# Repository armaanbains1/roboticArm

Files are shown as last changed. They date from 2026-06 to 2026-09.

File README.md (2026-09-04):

# Autonomous Object Tracking Robotic Arm

An autonomous eye-to-hand robotic pick-and-place platform combining computer vision object localization with custom embedded kinematics.
https://youtu.be/r0ZwZUzKdPA

---

## 🛠️ Project Overview

* **What it does:** This project is a full-stack, 6-DOF autonomous robotic arm that utilizes computer vision to localize objects in a physical workspace and translate those visual data points into real-world coordinate targets. 

* **System Evolution:** The platform was engineered iteratively across three distinct design phases:
  * **Version 1 (Joint Control):** Built the baseline forward-kinematic engine, mapping analog potentiometer inputs directly to manual multi-servo positioning.
  * **Version 2 (Coordinate Control):** Developed a custom geometric Inverse-Kinematic (IK) engine, allowing the robot to receive any absolute $(X, Y, Z)$ Cartesian coordinate and solve the required joint angles natively on-chip.
  * **Version 3 (AI Integration):** Combined the inverse-kinematic engine with an overhead camera pipeline running a custom-trained YOLOv8 object detection model, enabling the platform to autonomously locate, calculate spatial trajectories for, and pick up target objects.

* **The Core Stack:** C++, Python, OpenCV, YOLOv8, PySerial, ESP32, MG996R Servos, Autodesk Fusion 360 (CAD)

---

## 🦾 Kinematics & Firmware Architecture

This layer manages hardware actuation, real-time signal processing, and multi-joint coordination. By handling calculation pipelines natively on the microcontroller, the system avoids relying on resource-heavy operating middleware (like ROS) and ensures deterministic response times.

### 1. Embedded Control Stack (ESP32)
The low-level electronics architecture is built around an **ESP32 microcontroller** configured to manage real-time multi-servo communication and asynchronous host commands.

* **Multi-Servo PWM Generation:** To drive the physical linkages under continuous load without signal jitter, I utilized the ESP32's hardware-based LEDC peripheral. The stack configures **5 independent PWM channels** running at a base frequency of **50 Hz** with a high-resolution **12-bit depth** (mapping to a discrete duty cycle scale of 0 to 4095). This resolution allows for fractional joint adjustments. Actuators are mapped to dedicated GPIO targets across the bicep, forearm, base shoulder, wrist hand, and gripper assemblies.
* **Non-Blocking Serial Architecture:** The main execution routine processes incoming coordinate updates over the hardware serial line at a baud rate of **115,200**. Instead of using blocking execution methods like standard `delay()` calls which halt the CPU, the firmware handles inputs dynamically within the `loop()` cycle. 
* **Dynamic Servo Smoothing:** When a coordinate packet arrives, the script compares the new duty cycle target against the current positions (`prevDutyBicep != dutyBicep`). If a change is detected, the micro stepped-iterates through the duty array smoothly, applying discrete incremental adjustments. This approach prevents massive instantaneous voltage spikes from dropping the power rail, eliminates abrupt mechanical tearing, and generates smooth, predictable 3D paths.

### 2. Custom Inverse Kinematics (IK) Engine
Rather than relying on pre-built robotics toolkits, I designed and coded a custom math engine from scratch to bridge the gap between abstract 3D spatial coordinates and raw actuator joint angles.

* **Actuator Range Mapping & Stall Prevention:** The first step required profiling the physical boundaries of each linkage. For instance, the base shoulder servo operates across a 180-degree physical sweep, which I explicitly mapped to a safe hardware duty cycle range between **105 and 520**. Establishing these strict software-level constraints ensured the actuators would never push past mechanical end-stops, preventing servo stall conditions, minimizing high current spikes, and protecting the power rail from thermal tripping.

* **The Kinematics Baseline (Geometric Shadowing):**
  To develop an intuition for the physical workspace, I built a baseline Forward Kinematics engine driven by analog potentiometer inputs. I utilized these manual joint positions to calculate how much physical length each arm segment projected down onto the 2D surface of the desk—essentially treating the bicep and forearm linkages as hypotenuses of moving triangles. By continuously resolving these dynamic variables (`bicepLength` and `forearmLength`), the firmware calculated the combined radius of the arm extension. Multiplying this cumulative distance by the sine and cosine of the base shoulder angle provided a real-time, mathematical estimate of exactly where the end-effector was in space.

* **Transitioning to 3D Inverse Kinematics (IK):**
  Once the forward geometry was verified, I inverted the mathematical pipeline to implement true target-driven Inverse Kinematics. The core objective was to feed an absolute Cartesian vector `(X, Y, Z)` from the computer vision pipeline into the ESP32 and force the microcontroller to solve the required actuator positions backwards. 
  
  The engine first parses the targeted position, isolates the base rotation matrix to aim the shoulder, and then breaks down the required vertical depth profile. By evaluating the necessary linear extension across the $Z$-axis, the script determines the exact physical posture the bicep must take. Once the required bicep posture is locked in, the firmware uses the geometric properties established during the forward phase to run a reverse lookup—mapping the spatial requirements directly back into a discrete 12-bit hardware duty cycle. This exact same triangulation process is executed simultaneously across the forearm, bicep, and base shoulder joints to align the entire linkage assembly in a single clock cycle.

* **Dynamic Z-Axis Leveling & End-Effector Stabilization:**
  The wrist/hand assembly required a completely separate tracking system to manage physical picks cleanly. If the hand remained fixed relative to the forearm, moving the bicep or forearm would cause the gripper to tilt wildly, scraping the table surface or approaching the object at an unusable angle. To achieve true parallel Z-axis self-leveling, the firmware actively monitors the real-time changes in both the bicep and forearm duty cycles. It then dynamically calculates a counteracting offset and applies it directly to the wrist hand servo. This continuous, real-time stabilization loop counteracts any intermediate joint elevation shifts, keeping the gripper locked in a stable, perfectly vertical downward-facing orientation throughout the entire 3D travel arc.

---

## 👁️ Computer Vision & Coordinate Mapping

This module bridges the gap between what the overhead camera sees and where the physical arm moves. Transforming raw digital pixel coordinates from a video stream into absolute physical destinations requires balancing deep learning inference with geometric transformation pipelines.

### 1. Object Detection (YOLOv8)
To allow the robot to identify targets autonomously, I trained a custom **YOLOv8** object detection model (`best.pt`) optimized specifically to localize a green desk eraser. 
* **The Dataset & Training:** I generated a custom image dataset capturing the object under varying lighting conditions, baseline shifts, and shadows. The model was trained locally over **50 epochs**.
* **Performance:** The resulting weights are highly optimized for local inference, consistently outputting bounding boxes with a localized confidence threshold **above 83%**. The center point of this bounding box provides the raw `(pixel_x, pixel_y)` anchor for the rest of the mapping stack.

---

### 2. Pixels-to-Millimeters Transformation (Homography)
To translate a raw 2D pixel coordinate into an absolute physical location, I implemented a $3 \times 3$ projective **Homography Matrix** using OpenCV (`cv2.getPerspectiveTransform`). This maps the four clicked pixel corners of the camera view directly to a rigid $600\text{ mm} \times 380\text{ mm}$ physical whiteboard grid boundary on my desk.

* **The Calibration Trap (The Sequence Bug):** During integration, I hit a massive roadblock where the calculated $X$-axis coordinates were dead-on, but the $Y$-axis distances consistently overstretched reality by nearly $2\text{ cm}$. 
  
  The culprit was an order-of-operations bug in my vision script: I was generating the `homography_matrix` using corner coordinates captured from a pre-processed canvas, but the script was calculating the matrix *before* actually performing the 90-degree clockwise frame rotation and $1280 \times 720$ canvas resizing on the live image feed. This mismatch caused OpenCV's backend math to scale coordinates using uninitialized canvas dimensions, distorting the aspect ratio projection map. Moving the image rotation and resizing logic to the absolute top of the pipeline—before any transformation matrices are built—completely resolved the core spatial warp.

---

### 3. Static Camera Angle Calibration
Initially, running tests using a hand-held smartphone camera introduced too many variables; minor shifts in hand posture or lens tilt completely invalidated the perspective map between test runs. Moving to a **rigid, completely static overhead camera mount** was critical to lock down a permanent mathematical model of the workspace.

* **Fixing Lens Projection Tilt:**
  Even with a fixed mount, a camera lens positioned at a slight angle introduces a predictable perspective distortion, stretching the calculated $Y$-values further away from the lens. Because the view is completely static, I was able to isolate and resolve this using linear scaling.
  
  By placing the target at a known physical distance ($15.2\text{ cm}$) and measuring the script's raw homography output ($16.8\text{ cm}$), I calculated a permanent corrective multiplier:
  
  $$\text{Scaling Factor} = \frac{15.2}{16.8} \approx 0.90476$$
  
  Multiplying the raw centimeter outputs by `0.90476` across the entire $Y$-axis compresses the perspective tilt perfectly, creating dead-accurate spatial tracking across all quadrants of the workspace.

---

## 📐 Mechanical & Structural Design

* **Linkage Dimensions:** Bicep = `13.5 cm` | Forearm = `16.5 cm`
* **Stability:** All components were designed and 3D printed by myself. Everything was designed to be able to be attached to my table, and be used correctly. 
* **Design Files:** All design files are included in the CAD section of the repository
* **Gripper Design** The gripper was designed using rubber bands, a servo, and 2 sliding pads. The mechanism utilizes a high-torque servo to actively actuate two parallel sliding pads along a guided linear track. To guarantee a secure hold on  surfaces without adding excessive weight or mechanical complexity, I integrated elastic tension bands into the assembly. This setup provides passive compliance and consistent clamping pressure, while the sliding pads conform to the shape of the target object—ensuring slip-free, predictable pick-and-place execution.

---

## 📊 Experimental Validation (The Test Clips)

### Version 2.0: Hardware & Motion Baselines
* **Symmetrical Parity:** Movements across the center line (e.g., `15, 15`, `-15, 15`) to check trigonometric balancing.
* **The Geometric Workspace Sweep:** Tracing four different Xs to portray accuracy. 

### Version 3.0: Full Vision Integration + Object Pick Up (The Multi-Cam Layout)

Here, the robot will go to a specific position based on the coordinated it is fed by the AI model, pick up the object, drop it off at (10,10), and then return back to it's home position (20,0).

---

## 📁 Repository Structure
```text
├── cad/         # Parametric .STEP models and 3D print mesh files (.3mf / .stl)
├── firmware/    # C++ ESP32 firmware (Serial parsing, servo PWM, geometric IK)
├── vision/      # Python scripts (OpenCV processing, Homography matrix, YOLOv8 inference)
└── docs/        # Mathematical derivations and calibration notes

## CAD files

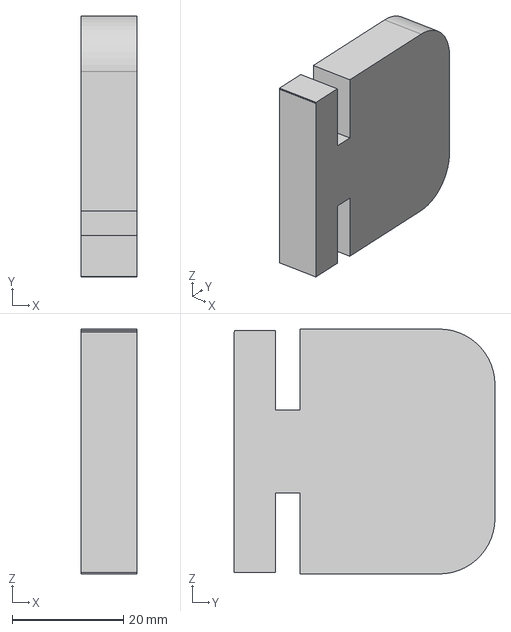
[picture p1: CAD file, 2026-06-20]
cadModels/GripperPadSTEP.step
10.0 x 46.9 x 44.0 mm

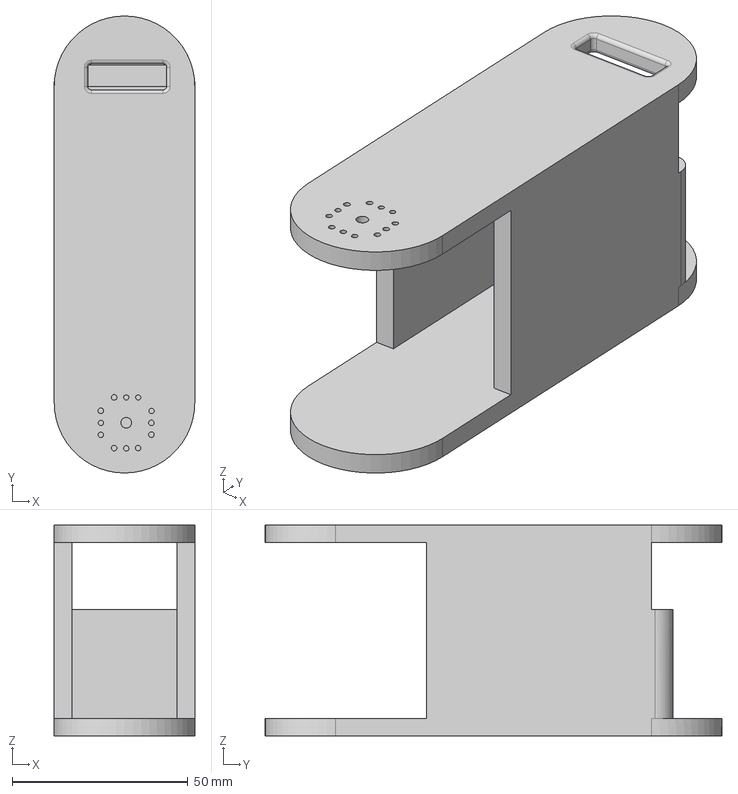
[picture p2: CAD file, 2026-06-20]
cadModels/bicepSTEP.step
40.0 x 130.0 x 60.0 mm

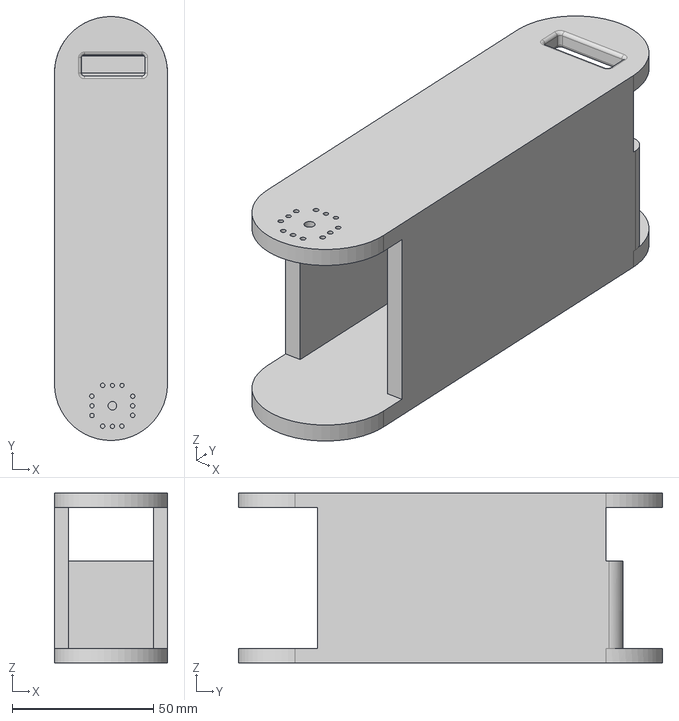
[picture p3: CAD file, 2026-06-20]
cadModels/forearmSTEP.step
40.0 x 150.0 x 60.0 mm

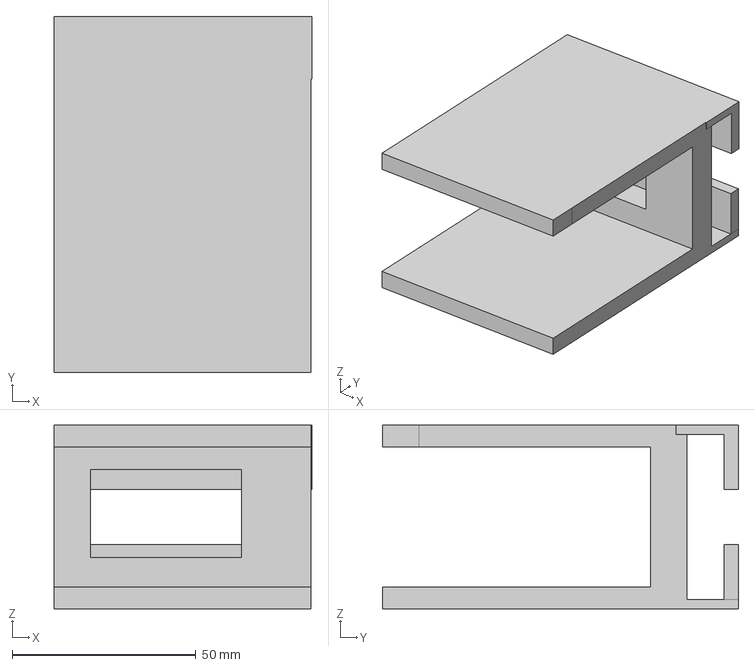
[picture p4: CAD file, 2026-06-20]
cadModels/handSTEP.step
70.2 x 97.0 x 50.0 mm

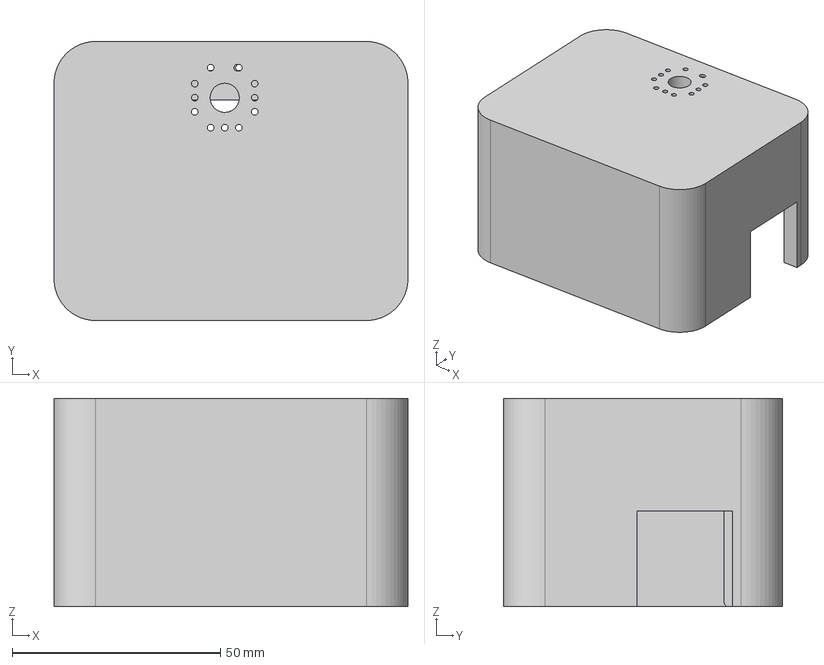
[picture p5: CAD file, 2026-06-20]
cadModels/shoulderSTEP.step
85.0 x 67.0 x 50.0 mm

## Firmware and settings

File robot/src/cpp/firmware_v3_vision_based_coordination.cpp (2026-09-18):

#include <Arduino.h>
#include <iostream>
#include <cmath> 

using namespace std;

double pi = 3.14159265358979323846;
double rad_to_deg = 180 / pi;
double deg_to_rad = pi / 180;

const int PWM_CHANNEL_BICEP = 0;
const int PWM_CHANNEL_FOREARM = 1;
const int PWM_CHANNEL_SHOULDER = 2;
const int PWM_CHANNEL_HAND = 3;
const int PWM_CHANNEL_GRIPPER = 4;

const int FREQ = 50;
const int PWM_RESOLUTION = 12;

const int MAX_DUTY_CYCLE = (int)(pow(2, PWM_RESOLUTION)) - 1;
const int GPIO_PIN = 18;


//bicep values

bool newDutyBicep = false;
int potValueBicep;
float duty_value_bicep;
int dutyBicep;
int prevDutyBicep;
double bicepLength;

//forearm values

bool newDutyForearm = false;
int potValueForearm;
float duty_value_forearm;
int dutyForearm;
int prevDutyForearm;
double forearmLength;

//shoulder values

bool newDutyShoulder = false;
int potValueShoulder;
float duty_value_shoulder;
int dutyShoulder;
int prevDutyShoulder;


//hand values

bool newDutyHand = false;
int potValueHand;
float duty_value_hand;
int dutyHand;
int prevDutyHand;


//gripper values

bool newDutyGripper = false;
int potValueGripper;
float duty_value_gripper;
int dutyGripper;
int prevDutyGripper;

//x,y calculation variables
int length = 0;

//position movement variables
std::pair<double,double> prevCoord;
std::pair<double, double> coord;

int prevDutyS = 0;
int prevDutyB = 0;
int prevDutyF = 0;
int prevDutyH = 0;

int dutyS = 0;
int dutyB = 0;
int dutyF = 0;
int dutyH = 0;

int zoffset = 10;

int baselineForarm = 500;
int baselineHand = 500;

// put function declarations here:


int inverseCalculateDutyShoulder(std::pair<double, double> coordinate){
    double dutyShoulder = 0;
    double degrees = 0;
    if (coordinate.first<0){
        cout << "smaller than 0" << endl;
        cout << atan2(coordinate.second, coordinate.first) << endl;
        degrees = ((atan2(coordinate.second, coordinate.first) * rad_to_deg)) - 90;
        dutyShoulder = ((degrees + 90.0) * 415.0 / 180.0) + 105.0;
    }
    else{
        cout << "greater than 0" << endl;
        cout << atan2(coordinate.second, coordinate.first) << endl;
        degrees = atan2(coordinate.second, coordinate.first) * rad_to_deg;
        dutyShoulder = ((degrees * 211.0) / 90.0) + 105.0;
    }
    return (int)dutyShoulder;
}


double calculateBicepLengthInv(std::pair<double, double> coord, double zoffset){
  // 9 = from height of gripper
  // 4 = height from bottom of base
  // 2 = height from item.
  double ground_dist = sqrt(pow(coord.first, 2) + pow(coord.second, 2));
  double length = sqrt(pow(ground_dist, 2) + pow(zoffset-5, 2));

  double max_reach = 29.99; // 13.5 (bicep) + 16.5 (forearm) - 0.01 to prevent floating point errors
  if (length > max_reach) {
      cout << length << " is greater than " << max_reach;
      cout << "WARNING: Target out of reach. Clamping bicep calculation." << endl;
      length = max_reach;
  }

  double angle = acos((pow(length, 2) + pow(13.5,2) - pow(16.5,2)) / (2*(length)*(13.5))) + atan((zoffset-5)/ground_dist);
  double lengthBicep = 13.5*cos(angle);
  return lengthBicep;
}

std::pair<double, double> calculateForearmLengthInv(std::pair<double, double> coord, double zoffset){
  double ground_dist = sqrt(pow(coord.first, 2) + pow(coord.second, 2));
  double length = sqrt(pow(ground_dist, 2) + pow(zoffset-5, 2));

  double max_reach = 29.99;
  if (length > max_reach) {
      cout << length << " is greater than " << max_reach;
      cout << "WARNING: Target out of reach. Clamping forearm calculation." << endl;
      length = max_reach;
  } 

  double angle = acos((pow(16.5, 2) + pow(length,2) - pow(13.5,2)) / (2*(length)*(16.5))) - atan((zoffset-5)/ground_dist);
  double lengthForearm = 16.5*cos(angle);
  std::pair<double, double> lengthAngle;
  lengthAngle.first = lengthForearm;
  lengthAngle.second = angle * (180.0 / 3.14159265358979323846);
  
  return lengthAngle;
}

int calculateBicepDuty(double bicepLength){
  int dutyBicep = (int)round((131.0 * ((90.0 - (acos(bicepLength / 13.5) / deg_to_rad)) / 90.0)) + 338.0);
  return dutyBicep;
}




int calculateForearmDuty(std::pair<double, double> lengthAngle, bool greater, int newDutyBicep, int prevDutyBicep, bool isNew){
  int dutyForearm = 0;
  int forearmAdjust = (newDutyBicep - prevDutyBicep) * 2.073;
  cout << "adjustment factor of " << forearmAdjust << endl;
  if (isNew){
    baselineForarm -= forearmAdjust;
  }

  if (lengthAngle.second <= 0){
    dutyForearm = (int)round((((acos(lengthAngle.first / 16.5) / deg_to_rad) / -30.0) * 111.0) - (baselineForarm)); 
  }
  else{
    dutyForearm = (int)round((baselineForarm) + (((acos(lengthAngle.first / 16.5) / deg_to_rad) / 45.0) * 118.0));  
  }   
  
  
  cout << " new forearm duty " << dutyForearm;
  return dutyForearm;
}

int calculateHandDuty(bool greater, int newDutyForearm, int prevDutyForearm, bool isNew){
    int handAdjust = (newDutyForearm - prevDutyForearm) * 1.0;
    cout << "adjustment factor of " << handAdjust << endl;
    if (isNew){
      baselineHand -= handAdjust;
  }
  return baselineHand;
}



double calculateBicepLength(){

  if (dutyBicep >= 338){
    bicepLength = 13.5 * cos(((double)(90.0 -(90.0*(double)(((dutyBicep - 338.0) / (469.0 - 338.0))))))*deg_to_rad);
  }
  else if (dutyBicep < 338){
    bicepLength = -13.5 * cos(((double)((dutyBicep/338.0)) * 90.0)*deg_to_rad);
  }
  return bicepLength;
}

double calculateForearmLength(){

  if (dutyForearm >= 223){
    forearmLength = 16.5 * cos((double)((double)((double)(dutyForearm - 223.0)/111.0)*-30.0)*deg_to_rad);
  }
  else{
    forearmLength = 16.5 * cos((double)((double)((double)(223.0-dutyForearm)/118.0)*45.0)*deg_to_rad);
  }
  return forearmLength;

}



void grip(){
    for (int duty_cycle = 180; duty_cycle <= 380 ; duty_cycle++){
      ledcWrite(PWM_CHANNEL_GRIPPER, duty_cycle);
      //delay(0);
    }
}

void ungrip(){
    for (int duty_cycle = 380; duty_cycle >= 180 ; duty_cycle--){
      ledcWrite(PWM_CHANNEL_GRIPPER, duty_cycle);
    }
}

void moveToTarget(std::pair<double,double> coord, std::pair<double,double> prevCoord, int newZoffset){
  Serial.print(zoffset); Serial.print(F(" and new ")); Serial.println(newZoffset);
  
  if (coord != prevCoord || newZoffset != zoffset) {
    Serial.println(F("new movement")); 
        
    dutyS = inverseCalculateDutyShoulder(coord);
    dutyB = calculateBicepDuty(calculateBicepLengthInv(coord, newZoffset));
    
    prevDutyS = inverseCalculateDutyShoulder(prevCoord);
    prevDutyB = calculateBicepDuty(calculateBicepLengthInv(prevCoord, zoffset));

    if (dutyB >= prevDutyB) {
        prevDutyF = dutyF;
        dutyF = calculateForearmDuty(calculateForearmLengthInv(coord, newZoffset), true, dutyB, prevDutyB, true);
    } else {
        prevDutyF = dutyF;
        dutyF = calculateForearmDuty(calculateForearmLengthInv(coord, newZoffset), false, dutyB, prevDutyB, true);
    }

    if (dutyF >= prevDutyF) {
        prevDutyH = dutyH;
        dutyH = calculateHandDuty(true, dutyF, prevDutyF, true);
    } else {
        prevDutyH = dutyH;
        dutyH = calculateHandDuty(false, dutyF, prevDutyF, true);
    }

    zoffset = newZoffset;

    int deltaS = abs(dutyS - prevDutyS);
    int deltaB = abs(dutyB - prevDutyB);
    int deltaF = abs(dutyF - prevDutyF);
    int deltaH = abs(dutyH - prevDutyH);

    int maxSteps = max(max(deltaS, deltaB), max(deltaF, deltaH));

    if (maxSteps == 0) return; 

    for (int step = 0; step <= maxSteps; step++) {
        float progress = (float)step / maxSteps; 

        int currentS = prevDutyS + (int)((dutyS - prevDutyS) * progress);
        int currentB = prevDutyB + (int)((dutyB - prevDutyB) * progress);
        int currentF = prevDutyF + (int)((dutyF - prevDutyF) * progress);
        int currentH = prevDutyH + (int)((dutyH - prevDutyH) * progress);

        ledcWrite(PWM_CHANNEL_SHOULDER, currentS);
        ledcWrite(PWM_CHANNEL_BICEP, currentB);
        ledcWrite(PWM_CHANNEL_FOREARM, currentF);
        ledcWrite(PWM_CHANNEL_HAND, currentH);

        delay(15); // Controls overall speed of the synchronized movement
    }

    Serial.print(F("prevDutyB=")); Serial.print(prevDutyB); Serial.print(F(" dutyB=")); Serial.println(dutyB);
    Serial.print(F("prevDutyF=")); Serial.print(prevDutyF); Serial.print(F(" dutyF=")); Serial.println(dutyF);
  } else {
    Serial.println(F("no new movement")); 
  }
}

void setup() {
  Serial.begin(115200);
  bicepLength = 14.5;
  // put your setup code here, to run once:
  ledcSetup(PWM_CHANNEL_BICEP, FREQ, PWM_RESOLUTION);
  ledcAttachPin(18, PWM_CHANNEL_BICEP);


  ledcSetup(PWM_CHANNEL_FOREARM, FREQ, PWM_RESOLUTION);
  ledcAttachPin(19, PWM_CHANNEL_FOREARM);


  ledcSetup(PWM_CHANNEL_SHOULDER, FREQ, PWM_RESOLUTION);
  ledcAttachPin(5, PWM_CHANNEL_SHOULDER); 

  ledcSetup(PWM_CHANNEL_HAND, FREQ, PWM_RESOLUTION);
  ledcAttachPin(4, PWM_CHANNEL_HAND); 


  ledcSetup(PWM_CHANNEL_GRIPPER, FREQ, PWM_RESOLUTION);
  ledcAttachPin(21, PWM_CHANNEL_GRIPPER); 

  prevCoord.first = 20.0;
  prevCoord.second = 2.5;
  prevDutyB = 338;
  prevDutyF = 500;
  prevDutyS = 105; //changed this to 90 from 105 
  prevDutyH = 500;

  //120
  dutyS = 105;

  dutyB = calculateBicepDuty(calculateBicepLengthInv(prevCoord, zoffset));
  cout << "initial dutyB" << dutyB << endl;
  dutyF = calculateForearmDuty(calculateForearmLengthInv(prevCoord, zoffset), true, dutyB, prevDutyB, true);
  cout << "initial dutyF" << dutyF << endl;
  dutyH = 500;
  cout << "initial dutyF" << dutyH << endl;




// starting point (20,0)


if (prevDutyB >= dutyB) {
      for (int duty_cycle = prevDutyB; duty_cycle >= dutyB ; duty_cycle--){
          ledcWrite(PWM_CHANNEL_BICEP, duty_cycle);
          delay(15);
      }
  } else {
      for (int duty_cycle = prevDutyB; duty_cycle <= dutyB ; duty_cycle++){
          ledcWrite(PWM_CHANNEL_BICEP, duty_cycle);
          delay(15);
      }
  }

  if (prevDutyF >= dutyF) {
      for (int duty_cycle = prevDutyF; duty_cycle >= dutyF ; duty_cycle--){
          ledcWrite(PWM_CHANNEL_FOREARM, duty_cycle);
          delay(15);
      }
  } else {
      for (int duty_cycle = prevDutyF; duty_cycle <= dutyF ; duty_cycle++){
          ledcWrite(PWM_CHANNEL_FOREARM, duty_cycle);
          delay(15);
      }
  }

  for (int duty_cycle = 0; duty_cycle <= 500 ; duty_cycle++){
      ledcWrite(PWM_CHANNEL_HAND, duty_cycle);
      delay(15);
  } 


  
  //delay(100);
/*
  for (int duty_cycle = 0; duty_cycle <= 25 ; duty_cycle++){
    ledcWrite(PWM_CHANNEL, duty_cycle);
    delay(1);
  }
*/

}

//std::pair<double, double> coordinateCalculator(){
    /*
  std::pair<double, double> coordinate;
  int angle = 0;
  double x = 0;
  double y = 0;
  if (dutyShoulder<316){
    angle = 90.0 * (((dutyShoulder-105.0) / (316.0-105.0)));
    x = length*sin(angle*deg_to_rad);
    y = length*cos(angle*deg_to_rad);
  }
  else{
    angle = (180.0 * (((dutyShoulder-105.0) / (520.0-105.0)))) - 90.0;
    y = length*sin(angle*deg_to_rad);
    x = -length*cos(angle*deg_to_rad);
  }
  coordinate.first = x;
  coordinate.second = y;
  return coordinate;
  */
//}


/*
std::pair<double, double> inverseCoordinateCalculator(std::pair<double, double> coordinate){
  std::pair<double, double> coordinate;
  int angle = 0;
  double x = 0;
  double y = 0;
  if (dutyShoulder<316){
    angle = 90.0 * (((dutyShoulder-105.0) / (316.0-105.0)));
    x = length*sin(angle*deg_to_rad);
    y = length*cos(angle*deg_to_rad);
  }
  else{
    angle = (180.0 * (((dutyShoulder-105.0) / (520.0-105.0)))) - 90.0;
    y = length*sin(angle*deg_to_rad);
    x = -length*cos(angle*deg_to_rad);
  }
  coordinate.first = x;
  coordinate.second = y;
  return coordinate;
}
*/
void loop() {
    // Only trigger if there is actual data waiting
    if (Serial.available() > 0) {
        
        double first = Serial.parseFloat();
        double second = Serial.parseFloat();
        double third = Serial.parseFloat();

        while (Serial.available() > 0 && isspace(Serial.peek())) {
            Serial.read(); 
        }

        char incomingKey = ' ';
        if (Serial.available() > 0) {
            incomingKey = Serial.read(); // Read the actual 'g' or 'u'
        }

        // Execute gripping logic
        if (incomingKey == 'g') {
            grip();
        } else if (incomingKey == 'u') {
            ungrip();
        }

        delay(2); 
        while (Serial.available() > 0) {
            Serial.read();
        }

        // Update coordinates
        coord.first = first;
        coord.second = second;
        coord.second += 2.5; 
        
        Serial.println(F("\n--- New Target Received ---"));
        Serial.print(F("Target X: ")); Serial.print(first);
        Serial.print(F(", Y: ")); Serial.print(second);
        Serial.print(F(", Z: ")); Serial.println(third);
        
        int targetDutyB = calculateBicepDuty(calculateBicepLengthInv(coord, third));
        
        Serial.print(F(" DUTY SHOULDER = ")); Serial.println(inverseCalculateDutyShoulder(coord));
        Serial.print(F(" DUTY BICEP = ")); Serial.println(targetDutyB);
        
        if (dutyB <= targetDutyB) {
            Serial.print(dutyB); Serial.print(F(" TO ")); Serial.print(targetDutyB); Serial.println(F(" new is greater"));
        } else {
            Serial.print(dutyB); Serial.print(F(" TO ")); Serial.print(targetDutyB); Serial.println(F(" old is greater"));
        }

        // Safety Bounds Check
        if ((targetDutyB > 460) || (targetDutyB < 299)) {
            Serial.println(F("Issue: Target out of physical bounds!"));
        } else {
            moveToTarget(coord, prevCoord, third);
            prevCoord = coord;
        }  
    }
    
    delay(50);
}
  

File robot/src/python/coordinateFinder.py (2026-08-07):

import cv2
import numpy as np
from ultralytics import YOLO

model = YOLO("best.pt") 

IMAGE_PATH = "image (3).webp" 


TABLE_WIDTH_MM = 600.0   
TABLE_HEIGHT_MM = 380.0 


TOP_LEFT_PIXEL     = [140, 44]  
TOP_RIGHT_PIXEL    = [1148, 77]  
BOTTOM_RIGHT_PIXEL = [1130, 506]  
BOTTOM_LEFT_PIXEL  = [123, 482]   

  

src_pts = np.float32([TOP_LEFT_PIXEL, TOP_RIGHT_PIXEL, BOTTOM_RIGHT_PIXEL, BOTTOM_LEFT_PIXEL])
dst_pts = np.float32([[0, 0], [TABLE_WIDTH_MM, 0], [TABLE_WIDTH_MM, TABLE_HEIGHT_MM], [0, TABLE_HEIGHT_MM]])
homography_matrix = cv2.getPerspectiveTransform(src_pts, dst_pts)

frame = cv2.imread(IMAGE_PATH)

if frame is not None:
    frame = cv2.rotate(frame, cv2.ROTATE_90_CLOCKWISE)
    frame = cv2.resize(frame, (1280, 720))
else:
    print(f"Error: Could not look up or read the file at '{IMAGE_PATH}'. Check the filename!")
    exit()

results = model(frame, verbose=False)


for r in results:
    if len(r.boxes) == 0:
        print("No eraser detected in this frame.")
        
    for box in r.boxes:
        x1, y1, x2, y2 = map(int, box.xyxy[0])
        confidence = float(box.conf[0])
        
        pixel_x = (x1 + x2) // 2
        pixel_y = (y1 + y2) // 2
        
        pixel_point = np.array([[[pixel_x, pixel_y]]], dtype=np.float32)
        real_world_point = cv2.perspectiveTransform(pixel_point, homography_matrix)
                
        raw_mm_x = real_world_point[0][0][0]
        raw_mm_y = real_world_point[0][0][1]
        

        cm_x = (raw_mm_x - 300.0) / 10.0  
        cm_y = raw_mm_y / 10.0

        print(f"  -> Pixel Position:  X={pixel_x}, Y={pixel_y}")
        print(f"  -> Table Position:  X={cm_x:.1f}cm, Y={cm_y:.1f}cm")
        print(f"  -> Confidence:      {confidence:.2%}")
        
        cv2.rectangle(frame, (x1, y1), (x2, y2), (0, 255, 0), 2)
        cv2.circle(frame, (pixel_x, pixel_y), 5, (0, 0, 255), -1)
        ui_label = f"X: {cm_x:.1f}cm Y: {cm_y:.1f}cm"
        cv2.putText(frame, ui_label, (x1, y1 - 10), cv2.FONT_HERSHEY_SIMPLEX, 0.5, (0, 255, 0), 2)

calibration_pts = np.array([TOP_LEFT_PIXEL, TOP_RIGHT_PIXEL, BOTTOM_RIGHT_PIXEL, BOTTOM_LEFT_PIXEL], np.int32)
calibration_pts = calibration_pts.reshape((-1, 1, 2))
cv2.polylines(frame, [calibration_pts], isClosed=True, color=(255, 0, 0), thickness=2)

cv2.imshow("Static Image AI Localization", frame)
print("\nPress any key while looking at the image window to close it.")
cv2.waitKey(0)
cv2.destroyAllWindows()

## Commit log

2026-05-25 safety measures to ensure servos stay within range
2026-06-12 Add firmware for potentiometer calibration of robotic arm
    This file implements the firmware for potentiometer calibration of a robotic arm, including setup and control for bicep, forearm, shoulder, hand, and gripper movements.
2026-06-12 Add inverse coordinator firmware for robotic arm
    Implement inverse kinematics for robotic arm control, allowing us to input any coordinate, and for the robot to go to that exact spot.
2026-06-12 Create gripTester.cpp
    Used for testing the grip of the gripper servo, which grabs onto objects
2026-06-20 Enhance README with Kinematics and Vision details
    Expanded the README to include detailed sections on Kinematics & Firmware Architecture, Object Detection, and Camera Angle Calibration, enhancing clarity on system design and functionality.
2026-06-20 Enhance README with detailed IK engine explanation
    Expanded the Custom Inverse Kinematics section with detailed explanations of the IK engine, mapping angles to PWM ranges, and the implementation of z-axis movement.
2026-09-04 Change project title to 'Autonomous Object Tracking Robotic Arm'
    Updated project title in README.
